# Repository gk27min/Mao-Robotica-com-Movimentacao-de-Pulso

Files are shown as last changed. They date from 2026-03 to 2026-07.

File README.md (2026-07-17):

# 🤖 Mão Robótica com Movimentação de Pulso — LIBRAS-BOT / FalaComaMão

> Protótipo de mão robótica de baixo custo, com cinco dedos funcionais e rotação de
> pulso, capaz de reproduzir configurações de mão (CMs) da **Língua Brasileira de Sinais
> (LIBRAS)** a partir de comandos de **voz ou texto**, interpretados por um modelo de
> linguagem (LLM) local.

Projeto desenvolvido para a disciplina de **Projeto Integrado em Computação II (PIC2)**
do curso de **Engenharia de Computação** da **Universidade Federal do Espírito Santo
(UFES)**.

**Status do projeto:** ✅ **Finalizado / funcional.**

🔗 **Repositório público (GitHub):**
<https://github.com/gk27min/Mao-Robotica-com-Movimentacao-de-Pulso>

<p align="center">
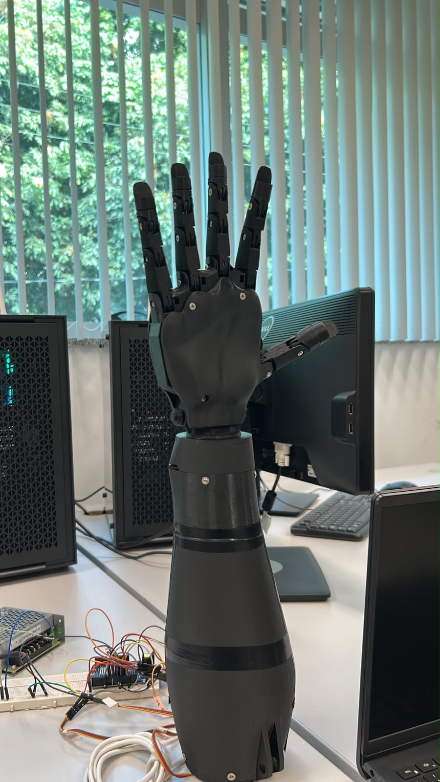
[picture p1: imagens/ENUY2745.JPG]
Protótipo montado da mão robótica com pulso
  
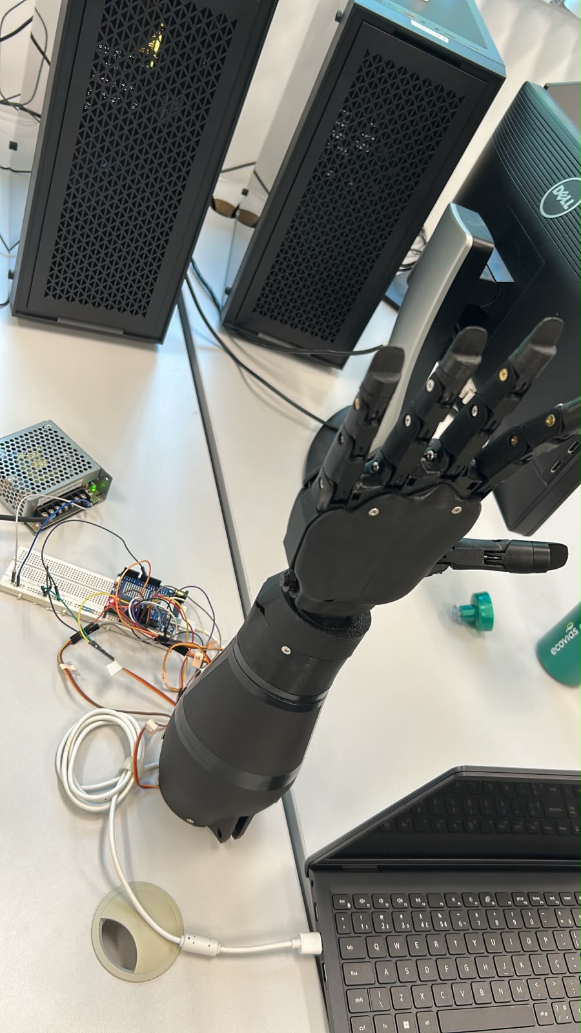
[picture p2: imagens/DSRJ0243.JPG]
Mão robótica conectada ao Arduino, fonte e notebook na bancada
  
</p>
<p align="center"><em>Protótipo final montado e a bancada de operação (Arduino Uno R4 WiFi, fonte, protoboard e servidor Python no notebook).</em></p>

---

## 📑 Índice

1. [Visão geral](#-visão-geral)
2. [Como funciona (fluxo end-to-end)](#-como-funciona-fluxo-end-to-end)
3. [Arquitetura do sistema](#-arquitetura-do-sistema)
4. [O que foi feito](#-o-que-foi-feito)
5. [O que foi usado (tecnologias)](#-o-que-foi-usado-tecnologias)
6. [Lista de equipamentos e componentes (BOM)](#-lista-de-equipamentos-e-componentes-bom)
7. [Hardware e ligações](#-hardware-e-ligações)
8. [Modelos 3D e peças impressas](#-modelos-3d-e-peças-impressas)
9. [Código-fonte — organização do repositório](#-código-fonte--organização-do-repositório)
10. [Guia de recriação (passo a passo)](#-guia-de-recriação-passo-a-passo)
11. [Biblioteca de gestos (CMs)](#-biblioteca-de-gestos-cms)
12. [Dificuldades de desenvolvimento](#-dificuldades-de-desenvolvimento)
13. [Vídeos e imagens de demonstração](#-vídeos-e-imagens-de-demonstração)
14. [Equipe e créditos](#-equipe-e-créditos)

---

## 🔎 Visão geral

A **FalaComaMão** é uma mão robótica antropomórfica impressa em 3D que traduz linguagem
natural em gestos de LIBRAS. O usuário fala ou digita uma frase no aplicativo; um LLM
rodando **localmente** interpreta a intenção e a converte em um código de gesto; esse
código é enviado por rede até um servidor Python, que o retransmite via **Bluetooth Low
Energy (BLE)** para um Arduino, o qual aciona os seis servomotores para reproduzir a
configuração de mão correspondente.

O foco do projeto é **acessibilidade e comunicação** a um **custo muito inferior** ao de
soluções comerciais, usando exclusivamente hardware aberto, impressão 3D e software livre.

---

## ⚙️ Como funciona (fluxo end-to-end)

```
┌─────────────┐   Voz/Texto   ┌──────────────────┐   HTTP/JSON   ┌─────────────────┐
│  App Flutter │ ────────────► │  Servidor Python │ ────────────► │  LLM local       │
│ (FalaComaMão)│   /api/comando│    (FastAPI)     │               │  Ollama (llama3.1)│
└─────────────┘               └──────────────────┘◄────────────  └─────────────────┘
       ▲                              │   código do gesto (ex.: 7)
       │ feedback no chat             │
       │                              ▼  BLE (bytearray[código])
       │                       ┌──────────────────┐    PWM     ┌─────────────────┐
       └───────────────────────│  Arduino Uno R4  │ ─────────► │ 6× Servo MG995   │
                               │      WiFi (BLE)  │            │ (5 dedos + pulso)│
                               └──────────────────┘            └─────────────────┘
```

1. **Captura** — o app captura a fala (Speech-to-Text nativo) ou o texto digitado.
2. **Interpretação** — o servidor Python envia a frase ao **Ollama**; o LLM escolhe **um
   único gesto** da biblioteca e responde no formato `GESTO: <ID>`. Há um *fallback* por
   palavras-chave caso o LLM não responda.
3. **Transmissão** — o servidor envia o código do gesto (1 byte) via **BLE** para o
   Arduino.
4. **Atuação** — o firmware decodifica o byte, resolve os ângulos de cada dedo/pulso e
   comanda os servomotores. Ao final, a mão retorna à posição de descanso.
5. **Feedback** — o app mostra o andamento no chat (*Analisando… → Mão executando → ✔*).

---

## 🏗️ Arquitetura do sistema

| Camada | Tecnologia | Papel |
|---|---|---|
| **Interface (mobile)** | Flutter / Dart | Chat multiplataforma, entrada por voz e texto, biblioteca de gestos |
| **Voz (STT)** | `speech_to_text` (Flutter) | Transcrição de áudio em tempo real |
| **Inteligência** | Ollama + `llama3.1` (LLM local) | Interpreta a intenção e escolhe o gesto |
| **Backend / ponte** | Python + FastAPI + Bleak | Orquestra a lógica e faz a ponte BLE com o Arduino |
| **Firmware** | C++ (Arduino) + `ArduinoBLE` + `Servo.h` | Recebe o código e aciona os servomotores |
| **Hardware** | Arduino Uno R4 WiFi + 6× MG995 | Estrutura física impressa em 3D com tração por fio de nylon |

---

## ✅ O que foi feito

- **Aplicativo mobile "FalaComaMão"** em Flutter, com duas telas: *Conversa* (chat com
  entrada por voz e texto) e *Biblioteca* (grade com todos os gestos disponíveis, com
  ícones animados que representam a configuração de cada mão).
- **Servidor intermediário em Python (FastAPI)** que expõe dois endpoints
  (`/api/comando` para linguagem natural e `/api/gesto` para envio direto de um código) e
  mantém uma conexão BLE persistente com reconexão automática.
- **Camada de inteligência** com *Prompt Engineering* sobre o Ollama para mapear frases
  livres em códigos de gesto, incluindo resolução de contas simples (ex.: "1 + 1" → gesto
  de dois dedos) e *fallback* determinístico por palavras-chave.
- **Firmware em C++** para o Arduino Uno R4 WiFi, que controla 6 servomotores via PWM,
  implementa gestos estáticos e gestos dinâmicos (com repetição de dedos e oscilação de
  pulso) e recebe comandos via BLE.
- **Estrutura física** impressa em 3D (PETG), com sistema de tração por fio de nylon e
  molas de retorno, adaptações de roldanas nos servos e caixa de pulso com rotação.
- **Biblioteca de ~20 configurações de mão (CMs)**, espelhada de forma idêntica entre app,
  backend e firmware (mesmos códigos em toda a stack).

<p align="center">
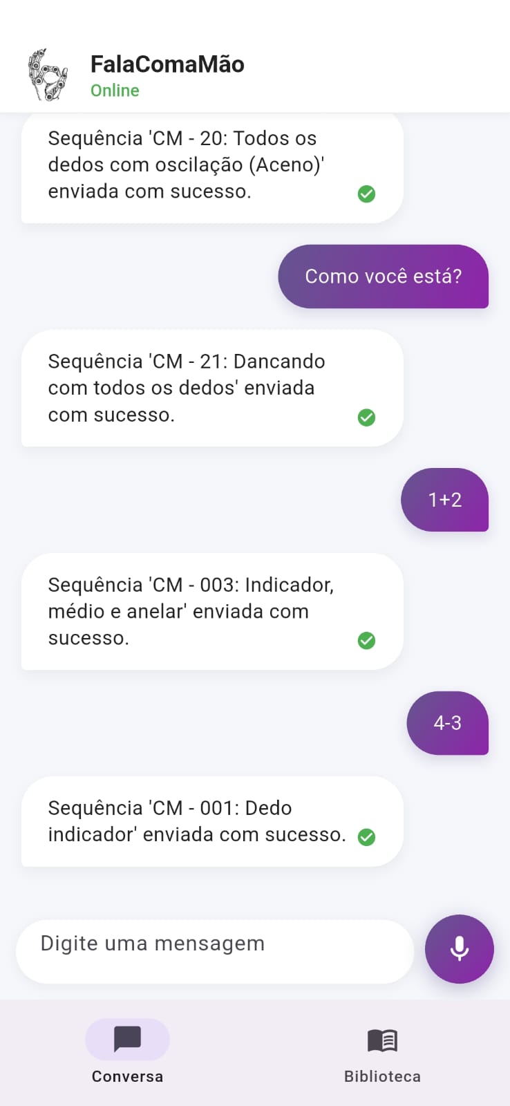
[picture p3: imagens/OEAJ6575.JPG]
Tela de conversa do app FalaComaMão
  
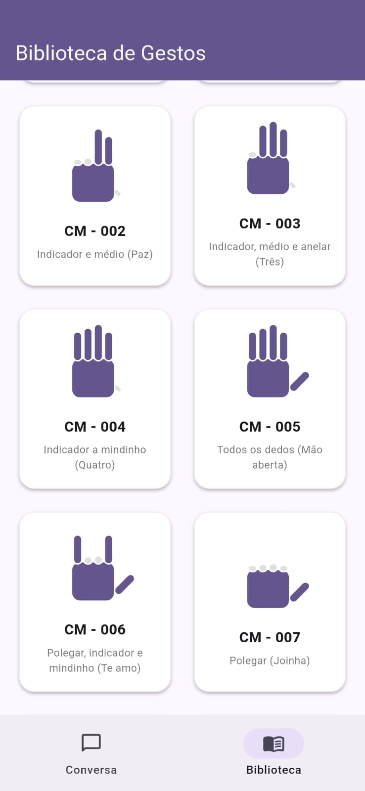
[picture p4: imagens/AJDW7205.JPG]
Tela biblioteca de gestos do app
  
</p>
<p align="center"><em>App FalaComaMão: tela de conversa (voz/texto) e biblioteca de gestos.</em></p>

---

## 🧰 O que foi usado (tecnologias)

**Software**

- **Flutter / Dart** — app multiplataforma (Android).
  Pacotes: `speech_to_text` (STT) e `http`.
- **Python 3.12** — backend.
  Pacotes principais: `fastapi`, `uvicorn`, `bleak` (BLE), `ollama`, `pydantic`
  (ver `backend/requirements.txt`).
- **Ollama** com o modelo **`llama3.1`** rodando localmente (sem nuvem).
- **C++ (Arduino IDE)** — firmware. Bibliotecas: `ArduinoBLE` e `Servo.h`.

**Protocolos e comunicação**

- **HTTP/JSON** entre app e servidor Python.
- **Bluetooth Low Energy (BLE / GATT)** entre servidor Python e Arduino.

**Fabricação**

- **Impressão 3D** em filamento **PETG**.
- Tração por **fio de nylon**, **molas de tração** sob medida e **roldanas** adaptadas.

---

## 📦 Lista de equipamentos e componentes (BOM)

### Eletrônica e atuadores

| Item | Especificação | Qtd. | Observação |
|---|---|:---:|---|
| **Microcontrolador** | **Arduino Uno R4 WiFi** | 1 | Comunicação por **BLE** com o servidor Python |
| **Servomotores** | **MG995** (torque metálico) | 6 | 5 dedos + 1 pulso, controlados por PWM |
| Fonte de alimentação | Fonte chaveada 5–6 V (corrente suficiente p/ 6 servos) | 1 | Alimenta os servos separadamente do Arduino |
| Protoboard | Padrão | 1 | Distribuição de alimentação e sinais |
| Jumpers / cabos | Macho-fêmea e macho-macho | — | Ligações de sinal e alimentação |
| Cabo USB | USB-C / USB | 1 | Programação e alimentação do Arduino |
| Smartphone Android | Físico (emulador não recomendado) | 1 | Roda o app; captura de áudio em tempo real |
| PC / notebook | Roda o servidor Python + Ollama | 1 | Precisa de BLE e estar na mesma rede do celular |

> ⚠️ Os servomotores devem ser alimentados por uma **fonte externa dedicada** (não pelos
> 5 V do Arduino), com **GND comum** entre a fonte e o Arduino. Seis MG995 sob carga
> podem exigir picos de corrente que a porta USB não fornece.

### Estrutura mecânica

| Item | Especificação | Qtd. |
|---|---|:---:|
| Filamento PETG | Preto | conforme impressão |
| **Fio de nylon** | Nylon **grosso** (~resistência de tração ≈ 50 kg) | rolo |
| **Molas de tração — dedos** | ver especificação em [Dificuldades](#-dificuldades-de-desenvolvimento) | 4 |
| **Molas de tração — polegar** | ver especificação em [Dificuldades](#-dificuldades-de-desenvolvimento) | 1 |
| Roldana / polia | 1 impressa sob medida + roldanas de fábrica dos servos | — |
| Parafusos | Diversos (fixação das peças) | — |

---

## 🔌 Hardware e ligações

### Microcontrolador

- **Arduino Uno R4 WiFi** — escolhido pela presença de **BLE nativo**, o que dispensa
  módulos externos de Bluetooth e permite receber os comandos diretamente do servidor
  Python.

### Mapa de pinos (servomotores → Arduino)

| Servo | Pino digital | Função |
|---|:---:|---|
| Pulso | **7** | Rotação/oscilação do pulso |
| Mindinho | **8** | Dedo mínimo |
| Anelar | **9** | Dedo anelar |
| Médio | **10** | Dedo médio |
| Indicador | **11** | Dedo indicador |
| Polegar | **12** | Polegar |

> **Lógica invertida (hardware):** por causa da montagem mecânica, mindinho/anelar/médio
> ficam **fechados a 180°** e **abertos a 0°**, enquanto o indicador é o oposto
> (**fechado a 0°**, **aberto a 180°**). Isso está documentado na função
> `configurarDedos()` do firmware.

### Comunicação BLE (GATT)

| Parâmetro | Valor |
|---|---|
| Nome do dispositivo | `MaoRobotica` |
| UUID do serviço | `19b10000-e8f2-537e-4f6c-d104768a1214` |
| UUID da característica (comando) | `19b10001-e8f2-537e-4f6c-d104768a1214` |
| Endereço MAC (exemplo do protótipo) | `b4:3a:45:b4:48:11` |
| Payload | 1 byte = código do gesto (ex.: `bytearray([7])`) |

> O MAC precisa ser atualizado em `backend/bluetooth_sender.py` para o do seu Arduino.

<p align="center">
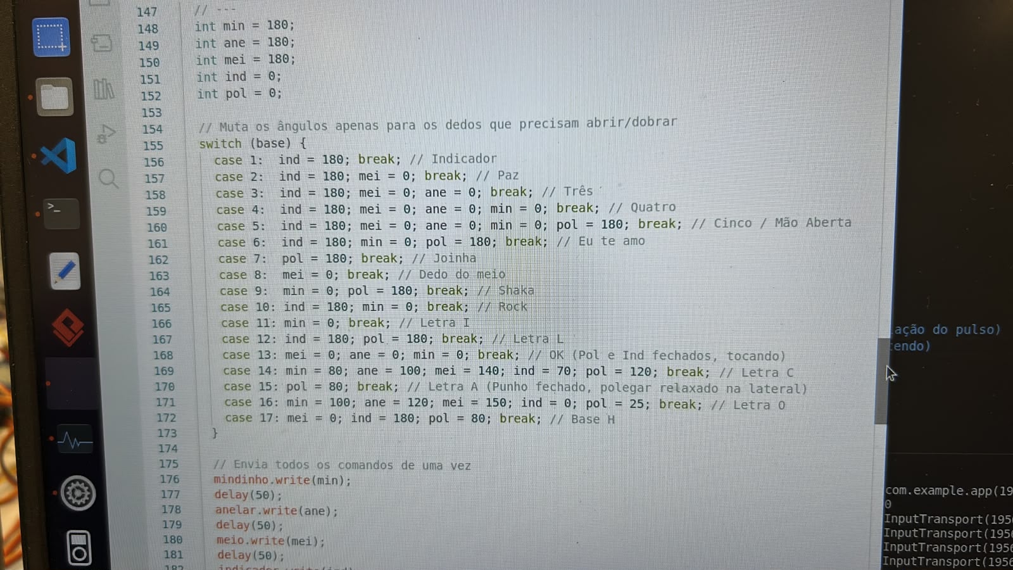
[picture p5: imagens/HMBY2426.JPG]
Trecho do firmware Arduino - configuração dos ângulos dos dedos
  
</p>
<p align="center"><em>Firmware C++: mapeamento de cada configuração de mão para os ângulos dos servos.</em></p>

---

## 🖨️ Modelos 3D e peças impressas

A estrutura mecânica é **impressa em 3D (PETG)** e parte do ecossistema aberto
**InMoov**, com **adaptações próprias** da equipe (roldana sob medida, ajustes de encaixe
e da caixa do pulso). Os arquivos `.stl` produzidos/utilizados estão versionados no
repositório em [`docs/3d_parts/`](docs/3d_parts).

<p align="center">
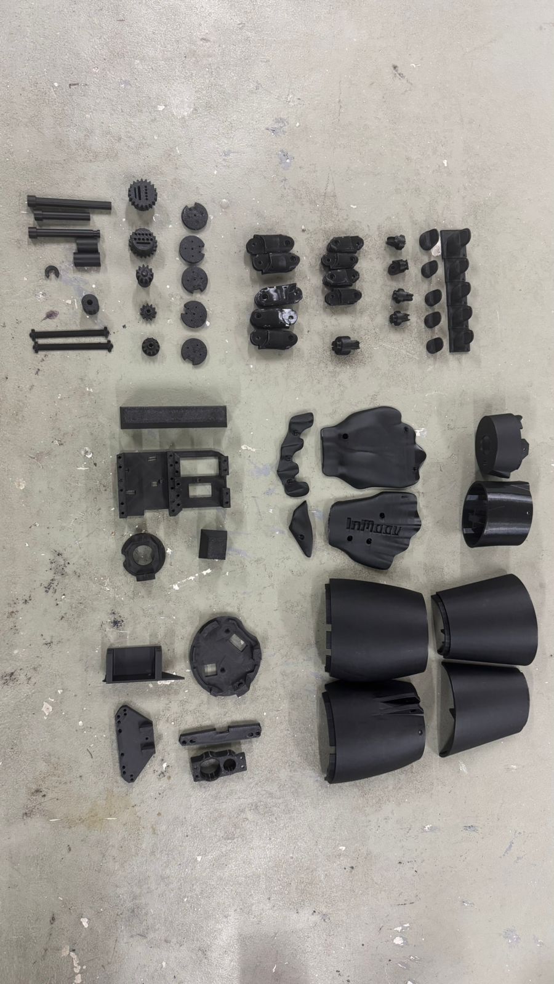
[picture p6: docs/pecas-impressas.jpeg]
Conjunto de peças impressas em 3D antes da montagem
  
</p>
<p align="center"><em>Conjunto de peças impressas em PETG antes da montagem (mão, dedos, pulso e suporte).</em></p>

**Mão e dedos — [`docs/3d_parts/mao/`](docs/3d_parts/mao)**

`i2_FingersX5V2`, `i2_FingersTipX5V2`, `i2_FingersMoldX5V3`, `i2_CoverFingerV3`,
`i2_HandCoverV1`, `i2_HandCoverV2`, `i2_PalmCoverV2`, `i2_WristGearV1`, `i2_WristLargeV2`.

**Pulso e antebraço — [`docs/3d_parts/pulso/`](docs/3d_parts/pulso)**

`robpart2V4`, `robpart3V4`, `robpart4V4`, `robpart5V4`, `robcap3V2`, `RobRingV3`,
`RobServoBedV6`, `RobCableFrontV3`, `RobCableBackV3`, `RotaWrist1V4`, `RotaWrist2V3`,
`RotaWrist3V3`, `WristGearsV5`, `Bolt_entretoise7`.

**Suporte — [`docs/3d_parts/suporte/`](docs/3d_parts/suporte)**

`Hand_stand.3mf` (base de apoio para exposição/testes).

---

## 🗂️ Código-fonte — organização do repositório

| Caminho | Linguagem / alvo | Descrição |
|---|---|---|
| [`app/`](app) | **Flutter / Dart** | Aplicativo mobile FalaComaMão |
| ↳ [`app/lib/main.dart`](app/lib/main.dart) | Dart | Interface completa: chat, STT, biblioteca de gestos e chamadas HTTP |
| [`backend/`](backend) | **Python (FastAPI)** | **Backend de produção** usado com o app |
| ↳ [`backend/server.py`](backend/server.py) | Python | API HTTP (`/api/comando`, `/api/gesto`) |
| ↳ [`backend/brain.py`](backend/brain.py) | Python | Mapeamento de intenção via LLM (Ollama) + fallback por keywords |
| ↳ [`backend/bluetooth_sender.py`](backend/bluetooth_sender.py) | Python | Ponte BLE (Bleak) com reconexão automática |
| ↳ [`backend/requirements.txt`](backend/requirements.txt) | — | Dependências do backend |
| [`server/`](server) | **Python (Flask)** | Protótipo inicial (etapa 1): Flask + Ollama + CRUD de sinais em `signs.json` |
| [`arduino/mao_robotica/mao_robotica.ino`](arduino/mao_robotica/mao_robotica.ino) | **C++ / Arduino Uno R4 WiFi** | **Firmware principal** (BLE + servos) |
| [`arduino/sinais_mao_robotica.ino`](arduino/sinais_mao_robotica.ino) | C++ / Arduino | Firmware alternativo focado em sinais |
| [`docs/`](docs) | — | Modelos 3D, esquemáticos, imagens e referências |

> **Nota sobre os dois servidores:** a pasta [`backend/`](backend) (FastAPI + BLE) é a que
> conversa com o app e com o Arduino no protótipo final. A pasta [`server/`](server)
> (Flask + Ollama) foi o **primeiro protótipo** da etapa de orquestração e é mantida como
> referência histórica.

---

## 🛠️ Guia de recriação (passo a passo)

### Pré-requisitos

- Impressora 3D e filamento **PETG**.
- **Arduino IDE** com a placa **Arduino Uno R4 WiFi** e as bibliotecas `ArduinoBLE` e
  `Servo`.
- **Python 3.12** e **Ollama** instalados no PC (com o modelo `llama3.1` baixado:
  `ollama pull llama3.1`).
- **Flutter SDK** e um **smartphone Android físico** (recomendado — o emulador tem
  incompatibilidades de microfone/KVM no Linux).

### 1. Fabricação e montagem mecânica

1. Imprima as peças de [`docs/3d_parts/`](docs/3d_parts) em PETG.
2. **Lixe os encaixes** que saírem imperfeitos da impressão (ver
   [Dificuldades](#-dificuldades-de-desenvolvimento)).
3. Passe o **fio de nylon grosso** pelos dedos e instale as **molas de tração** (specs
   abaixo).
4. Monte as **roldanas** nos servos (uma delas foi impressa sob medida sobre a roldana
   original do motor).
5. Fixe os 6 servos MG995 (5 dedos + pulso).

### 2. Firmware (Arduino)

1. Abra [`arduino/mao_robotica/mao_robotica.ino`](arduino/mao_robotica/mao_robotica.ino)
   na Arduino IDE.
2. Confira o [mapa de pinos](#mapa-de-pinos-servomotores--arduino) (pinos 7 a 12).
3. Carregue o firmware. No **Monitor Serial (9600 baud)** aparecerá o **endereço MAC** da
   placa — **anote-o**.

### 3. Backend (Python)

```bash
cd backend
python -m venv .venv
source .venv/bin/activate          # Linux/Mac  (Windows: .venv\Scripts\activate)
pip install -r requirements.txt
```

- Em [`backend/bluetooth_sender.py`](backend/bluetooth_sender.py), atualize o
  `MAC_ADDRESS` com o MAC anotado no passo anterior (e mantenha `MOCK_BLE = False` para
  usar o Arduino real).
- Garanta que o **Ollama** está rodando (`ollama serve`) com o `llama3.1` disponível.
- Suba o servidor:

```bash
uvicorn server:app --host 0.0.0.0 --port 5000 --reload
```

### 4. Aplicativo (Flutter)

1. Descubra o **IP do PC** na rede local (`ipconfig` no Windows / `ip a` no Linux).
2. Atualize esse IP em [`app/lib/main.dart`](app/lib/main.dart) (constantes `_serverUrl`
   e `serverUrl`, hoje em `http://192.168.1.4:5000`).
3. Ative a **depuração USB** no celular, conecte-o e rode:

```bash
cd app
flutter devices     # confirma que o celular foi reconhecido
flutter run
```

### 5. Teste end-to-end

- Fale ou digite "manda um joinha", "faz o sinal de paz", "abre a mão", "1 + 1"…
- A frase é interpretada, o código do gesto vai por BLE ao Arduino e a **mão executa** o
  movimento. O chat mostra o status até o ✔.

---

## ✋ Biblioteca de gestos (CMs)

Os códigos são **idênticos** no app, no backend e no firmware. Códigos **0–19** são
estáticos; **≥100** acionam também a **oscilação do pulso** (`código % 100` resolve a
configuração de dedos).

| Código | Configuração de mão | Exemplos de fala |
|:---:|---|---|
| 0 | Mão totalmente fechada (punho) | "fecha a mão", "3 − 3" |
| 1 | Dedo indicador | "aponta", "um" |
| 2 | Indicador e médio | "paz", "vitória", "1 + 1" |
| 3 | Indicador, médio e anelar | "três" |
| 4 | Indicador ao mindinho | "quatro" |
| 5 | Todos os dedos (mão aberta) | "abre a mão", "cinco", "pare" |
| 6 | Polegar, indicador e mindinho | "te amo", "ily" |
| 7 | Polegar | "joinha", "positivo", "valeu" |
| 9 | Polegar e mindinho | "hang loose", "telefone", "alô" |
| 10 | Indicador e mindinho | "rock", "metal" |
| 11 | Mindinho | "letra I" |
| 12 | Polegar e indicador | "letra L" |
| 13 | Médio, anelar e mindinho | "ok", "beleza", "perfeito" |
| 14–17 | Letras C, A, O e base do H | "letra C", "letra A", "letra O" |
| 18 | Sinal de água (indicador batendo) | "água", "beber" |
| 19 | Sinal de aspas (indicador e médio dobrando) | "aspas", "citação" |
| 20 / 105 | Todos os dedos com oscilação (aceno) | "oi", "olá", "tchau" |
| 100–119 | Versões dinâmicas (com oscilação do pulso) | — |

---

## 🧩 Dificuldades de desenvolvimento

Esta seção documenta honestamente os obstáculos enfrentados e as soluções adotadas — é a
parte mais valiosa para quem for **recriar** o projeto.

### 1. Fio de nylon

A movimentação dos dedos só ficou satisfatória usando um **fio de nylon mais grosso**,
com resistência de tração da ordem de **50 kg**. Fios mais finos não davam firmeza
suficiente ao movimento.

### 2. Molas de tração (sob medida)

As molas de retorno dos dedos têm um **tamanho muito específico** e **não foram
encontradas no mercado** — foi preciso **mandá-las fabricar**. Definir as propriedades
ideais foi um desafio: ângulos de gancho diferentes de **180° ou 0°** deixavam os dedos
**desalinhados** e o movimento "sujo". As especificações que funcionaram foram:

**Molas dos dedos normais** (quantidade: **4**)

| Propriedade | Valor |
|---|---|
| Diâmetro do arame (fio) | 0,5 mm |
| Diâmetro externo | 4,8 mm |
| Altura do corpo (sem ganchos) | 46 mm |
| Altura total (com ganchos) | 56 mm |
| Posição dos ganchos | alinhados (180°) |
| Material | aço carbono |
| Galvanizada | não |

**Mola do polegar (dedão)** (quantidade: **1**)

| Propriedade | Valor |
|---|---|
| Diâmetro do arame (fio) | 0,5 mm |
| Diâmetro externo | 4,8 mm |
| Altura do corpo (sem ganchos) | 42,5 mm |
| Altura total (com ganchos) | 52 mm |
| Posição dos ganchos | alinhados (180°) |
| Material | aço carbono |
| Galvanizada | não |

### 3. Roldanas (polias) dos servos

A **impressão da roldana não ficou perfeita** e o encaixe **não cabia no motor**. A
solução foi **fabricar uma roldana que se encaixa em volta da roldana original** que
acompanha o servo — assim o ajuste ficou perfeito.

### 4. Impressão 3D e estrutura

- Vários **encaixes precisaram ser lixados** após a impressão.
- As **partes centrais do braço não possuem parafusos**, o que consideramos um **ponto
  negativo** do projeto (perda de rigidez estrutural).
- A **caixa do motor do pulso não é bem estruturada** e possui uma **ponta que agarrou o
  fio de nylon** de um dos dedos, **tensionando demais o fio** — isso levou à **queima de
  um dos motores**. Recomendamos revisar/reforçar essa peça antes de operar sob carga.

---

## 🎬 Vídeos e imagens de demonstração

### Imagens

Todas na pasta [`imagens/`](imagens) e [`docs/`](docs):

| Arquivo | Conteúdo |
|---|---|
| [`imagens/ENUY2745.JPG`](imagens/ENUY2745.JPG) | Protótipo montado (mão aberta) |
| [`imagens/DSRJ0243.JPG`](imagens/DSRJ0243.JPG) | Bancada com Arduino, fonte e servidor |
| [`imagens/OEAJ6575.JPG`](imagens/OEAJ6575.JPG) | App — tela de conversa |
| [`imagens/AJDW7205.JPG`](imagens/AJDW7205.JPG) | App — biblioteca de gestos |
| [`imagens/HMBY2426.JPG`](imagens/HMBY2426.JPG) | Firmware — configuração dos dedos |
| [`docs/pecas-impressas.jpeg`](docs/pecas-impressas.jpeg) | Peças impressas em 3D |

### Vídeos

> Os vídeos de demonstração acompanham este repositório na pasta
> [`imagens/`](imagens). Substitua os nomes abaixo pelos arquivos reais:

| Vídeo | Conteúdo |
|---|---|
| `imagens/demo_voz.mp4` | Demonstração por **comando de voz** |
| `imagens/demo_gestos.mp4` | Execução de vários **gestos de LIBRAS** |
| `imagens/demo_pulso.mp4` | Movimentação/oscilação do **pulso** |

---

## 👥 Equipe e créditos

- Projeto acadêmico — **PIC2 · Engenharia de Computação · UFES**.
- Estrutura mecânica baseada no projeto de hardware aberto **InMoov**, com adaptações
  próprias da equipe.
- Licença: ver [`LICENSE`](LICENSE).

---

<p align="center"><em>FalaComaMão — tecnologia acessível a serviço da comunicação em LIBRAS.</em></p>

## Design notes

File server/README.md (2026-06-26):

# Backend Python — FalaComaMão / LIBRAS-BOT

Servidor intermediário que conecta o app Flutter, o **Ollama** (LLM local) e,
nas próximas etapas, o **Arduino R4 WiFi** via Bluetooth Low Energy.

## Arquitetura desta etapa (1)

```
  Flutter (texto NLP)
        │  HTTP POST /api/comando
        ▼
   app.py  ─────────────► ollama_client.py ──► Ollama (llama3.1:8b)
        │                                          │
        │◄─────── sinal escolhido + ângulos ───────┘
        │
        └── (etapa 4) BLE ──► Arduino R4 ──► servos
```

## Estrutura

| Arquivo | Função |
|---|---|
| `app.py` | Servidor Flask + endpoints REST |
| `ollama_client.py` | Cliente da API Ollama com prompt de classificação de intenção |
| `signs.json` | Sinais cadastrados (id, nome, descrição, sinônimos, ângulos) |
| `test_ollama.py` | REPL pra testar o cérebro sem precisar do Flutter nem do Arduino |
| `requirements.txt` | Dependências Python |

## Pré-requisitos

1. **Python 3.10+** (verifique com `python --version` no PowerShell).
2. **Ollama** rodando em `http://localhost:11434` com `llama3.1:8b` puxado:
   ```powershell
   ollama list      # deve aparecer llama3.1:8b
   ```

## Instalação

Abra o PowerShell na pasta `server/` e rode:

```powershell
# (Opcional, mas recomendado) crie um ambiente virtual:
python -m venv .venv
.\.venv\Scripts\Activate.ps1

# Instale as dependências:
pip install -r requirements.txt
```

> Se aparecer erro de execução de script no `Activate.ps1`, rode antes:
> `Set-ExecutionPolicy -Scope CurrentUser -ExecutionPolicy RemoteSigned`

## Teste rápido do cérebro (sem Flutter)

```powershell
python test_ollama.py
```

Digite frases — exemplos:

```
você> oi, tudo bem?         →  Oi  (id=oi)
você> falou, até mais         →  Tchau  (id=tchau)
você> show, beleza            →  OK  (id=ok)
você> que horas são?          →  nenhum sinal corresponde
```

Se isso funciona, a parte mais importante da etapa 1 está validada. ✔

## Rodando o servidor

```powershell
python app.py
```

Vai subir em `http://0.0.0.0:5000`. Pegue o IP do PC na rede (`ipconfig` →
"Endereço IPv4") e atualize a URL no Flutter em `app/lib/main.dart`.

### Endpoints disponíveis

| Método | Rota | O que faz |
|---|---|---|
| GET | `/api/status` | Saúde do servidor + Ollama |
| GET | `/api/sinais` | Lista os sinais cadastrados |
| POST | `/api/sinais` | Cadastra novo sinal (corpo JSON) |
| DELETE | `/api/sinais/<id>` | Remove um sinal |
| POST | `/api/comando` | Recebe texto → Ollama escolhe sinal → devolve ângulos |

### Exemplos de chamada (PowerShell)

Status:
```powershell
curl http://localhost:5000/api/status
```

Listar sinais:
```powershell
curl http://localhost:5000/api/sinais
```

Mandar um comando:
```powershell
curl -X POST http://localhost:5000/api/comando `
     -H "Content-Type: application/json" `
     -d '{"comando":"oi, tudo bem?"}'
```

Cadastrar um sinal novo:
```powershell
$body = @{
  id = "legal"
  nome = "Legal"
  descricao = "Sinalizar que algo é legal, maneiro, daora."
  sinonimos = @("daora","massa","maneiro","top")
  angulos = @{ polegar=180; indicador=0; medio=0; anelar=0; minimo=0; pulso=120 }
} | ConvertTo-Json
curl -X POST http://localhost:5000/api/sinais -H "Content-Type: application/json" -d $body
```

## Formato dos sinais (`signs.json`)

```jsonc
{
  "sinais": [
    {
      "id": "oi",                       // identificador único, snake_case
      "nome": "Oi",                     // exibição amigável
      "descricao": "Cumprimentar ...",  // o Ollama usa isso para decidir
      "sinonimos": ["olá", "salve"],    // ajuda o LLM a casar
      "angulos": {                      // 0..180 graus por servo
        "polegar": 0,
        "indicador": 180,
        "medio": 180,
        "anelar": 180,
        "minimo": 180,
        "pulso": 90
      }
    }
  ]
}
```

## Próximas etapas

- **2.** Telas de cadastro/biblioteca no Flutter consumindo `/api/sinais`.
- **3.** Firmware Arduino R4 com BLE + servos.
- **4.** Camada BLE no Python (`bleak`) — substituir o `TODO` em `app.py`.
- **5.** Polimento end-to-end (reconexão, feedback no app, logging).

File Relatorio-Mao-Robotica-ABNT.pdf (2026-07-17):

## UNIVERSIDADE FEDERAL DO ESPÍRITO SANTO CENTRO TECNOLÓGICO CURSO DE ENGENHARIA DE COMPUTAÇÃO

## DÉBORA AZEVEDO CAETANO GABRIELA BUTERI BELMOCK GESSICA DE SOUZA SILVA MARCOS VINICIUS DE SOUZA SILVA

# MÃO ROBÓTICA COM MOVIMENTAÇÃO DE PULSO

## Relatório técnico do projeto

## Vitória – ES

2026

## Débora Azevedo Caetano Gabriela Buteri Belmock Gessica de Souza Silva Marcos Vinicius de Souza Silva

# MÃO ROBÓTICA COM MOVIMENTAÇÃO DE PULSO

Relatório | técnico | apresentado | à

## disciplina de Projeto Integrado em Computação II (PIC2) do curso de

Engenharia | de | Computação | da
Universidade Federal do Espírito Santo, como requisito parcial de avaliação.

## Orientadores: Rodolfo da Silva Villaça e

Ricardo Carminati de Mello.

## Vitória – ES

2026

## SUMÁRIO

## APÊNDICE A – CÓDIGO-FONTE DO APLICATIVO (FLUTTER/DART)

APÊNDICE E – PROTÓTIPO INICIAL DO SERVIDOR (FLASK).........55

## 1 INTRODUÇÃO

## A comunicação por meio da Língua Brasileira de Sinais (LIBRAS) é

um direito das pessoas surdas e um pilar de acessibilidade. Entretanto,

dispositivos assistivos capazes de reproduzir sinais manuais ainda são caros e pouco acessíveis. Este relatório descreve o desenvolvimento de uma mão robótica de baixo custo, com cinco dedos funcionais e movimentação de pulso, capaz de reproduzir configurações de mão (CMs) empregadas em LIBRAS a partir de comandos em linguagem

natural, fornecidos por voz ou por texto.

O sistema integra hardware e software: uma estrutura mecânica impressa em 3D, acionada por seis servomotores; um microcontrolador que executa os movimentos; um servidor que interpreta a intenção do usuário com o apoio de um modelo de linguagem (LLM) executado localmente; e um aplicativo móvel que serve de interface. O protótipo

encontra-se finalizado e funcional.

## Figura 1 – Protótipo final montado


Fonte: os autores (2026).

## 1.1 Justificativa

## Soluções comerciais de mãos robóticas e próteses ativas possuem

custo elevado, o que limita seu uso em contextos educacionais e sociais. A proposta deste projeto é demonstrar que, com hardware aberto,

## impressão 3D e software livre, é possível construir um dispositivo

## funcional voltado à comunicação e à acessibilidade a uma fração do custo das alternativas de mercado, servindo também como plataforma

didática de robótica e sistemas embarcados.

## 1.2 Objetivos

## O objetivo geral é projetar e construir uma mão robótica capaz de reproduzir configurações de mão da LIBRAS a partir de comandos em linguagem natural. Como objetivos específicos, destacam-se: (i) desenvolver a estrutura mecânica impressa em 3D com dedos e pulso

articulados; (ii) implementar o firmware de controle dos servomotores;

## (iii) desenvolver o servidor de interpretação e a integração com um modelo de linguagem local; (iv) construir o aplicativo de interface com entrada por voz e por texto; e (v) integrar todas as camadas em um

fluxo funcional ponta a ponta.

## 1.3 Repositório do projeto

## Todo o código-fonte, os modelos 3D e a documentação estão disponíveis publicamente no repositório:

## github.com/gk27min/Mao-Robotica-com-Movimentacao-de-Pulso

## 2 VISÃO GERAL DO SISTEMA

## O sistema é organizado em camadas, da interface com o usuário até o acionamento físico dos motores. Cada camada tem uma responsabilidade bem definida e se comunica com a seguinte por um protocolo específico, o que facilita o teste e a manutenção de cada parte

de forma isolada.

## 2.1 Arquitetura

A arquitetura adotada é apresentada na Figura 2. O aplicativo captura a fala ou o texto do usuário e envia a frase, por HTTP, ao servidor Python. O servidor consulta um modelo de linguagem (LLM) executado localmente, que classifica a intenção e devolve o identificador do gesto correspondente. Em seguida, o servidor transmite esse identificador, por Bluetooth Low Energy (BLE), ao microcontrolador, que

aciona os servomotores por modulação por largura de pulso (PWM).

## Figura 2 – Arquitetura do sistema

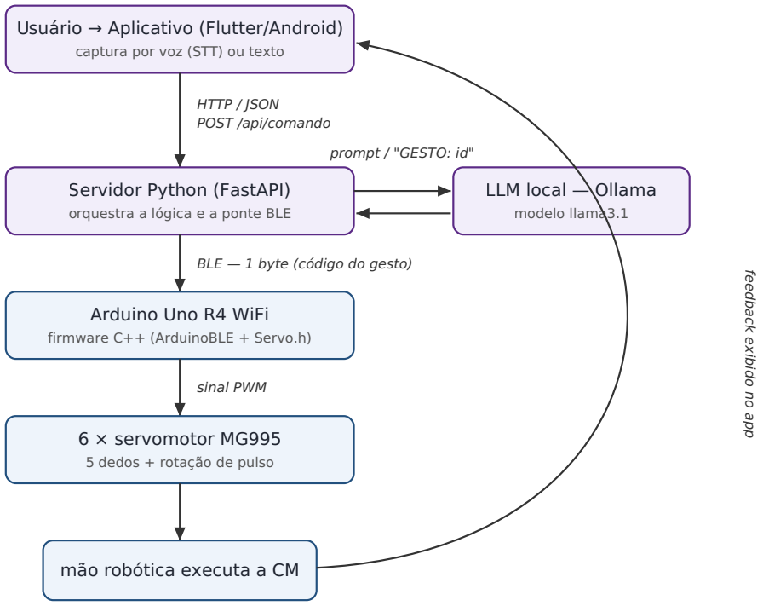
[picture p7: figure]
Usuário → Aplicativo (Flutter/Android); captura por voz (STT) ou texto; HTTP / JSON POST /api/comando; Servidor Python (FastAPI); orquestra a lógica e a ponte BLE; LLM local — Ollama; modelo llama3.1; prompt / "GESTO: id"; BLE — 1 byte (código do gesto); Arduino Uno R4 WiFi; firmware C++ (ArduinoBLE + Servo.h); sinal PWM; 6 × servomotor MG995; 5 dedos + rotação de pulso; mão robótica executa a CM; feedback exibido no app

Fonte: os autores (2026).

## 2.2 Fluxo de funcionamento

O funcionamento pode ser resumido em cinco etapas. Na captura,

o aplicativo obtém a fala (por reconhecimento de voz) ou o texto digitado. Na interpretação, o servidor envia a frase ao LLM, que escolhe um único gesto da biblioteca e responde no formato padronizado GESTO: <id>; caso o modelo não responda, um mecanismo de reserva por palavras-chave assume a decisão. Na transmissão, o servidor envia o código do gesto (um único byte) ao Arduino por BLE. Na atuação, o firmware decodifica o byte, calcula os ângulos de cada dedo e do pulso e comanda os motores; ao final, a mão retorna à posição de descanso. Por

fim, no retorno, o aplicativo exibe o andamento da operação ao usuário.

## 3 MATERIAIS E EQUIPAMENTOS

Esta seção relaciona os equipamentos, dispositivos eletrônicos, atuadores e materiais empregados na construção do protótipo.

## 3.1 Microcontrolador

O controle de baixo nível é realizado por um Arduino Uno R4 WiFi. Essa placa foi escolhida por oferecer Bluetooth Low Energy (BLE) nativo, o que dispensa módulos externos de comunicação sem fio e permite que o servidor envie os comandos diretamente à placa. O microcontrolador é responsável por receber o código do gesto, calcular

os ângulos e gerar os sinais PWM que acionam os servomotores.

## 3.2 Atuadores

Os movimentos são produzidos por seis servomotores MG995, de engrenagens metálicas: cinco deles tracionam os dedos (polegar,

## indicador, médio, anelar e mínimo) e um é responsável pela rotação/ oscilação do pulso. Os servos MG995 foram adotados por conciliarem torque adequado à tração dos dedos e baixo custo. Cada servo opera na

faixa de 0° a 180°, controlado por PWM a partir da biblioteca Servo.h.

## 3.3 Alimentação e componentes eletrônicos

Como seis servos sob carga demandam picos de corrente superiores ao que a porta USB fornece, os motores são alimentados por uma fonte externa dedicada, mantendo-se o GND comum com o Arduino. As ligações de sinal e de alimentação são distribuídas em uma protoboard, por meio de cabos jumper. O Quadro 1 relaciona os

componentes eletrônicos.

## Quadro 1 – Equipamentos e dispositivos eletrônicos

Item | Especificação | Qtd. | Função
Microcontrolador | Arduino Uno R4 WiFi | 1 | Controle e comunicação BLE
Servomotores | MG995 (engrenagem metálica) | 6 | 5 dedos + pulso (PWM)
Fonte de alimentação | Fonte chaveada (5–6 V, corrente p/ 6 servos) | 1 | Alimentação dos servos
Protoboard | Padrão | 1 | Distribuição de sinais e energia
Cabos jumper | Macho-macho / macho-fêmea | – | Ligações elétricas
Cabo USB | USB | 1 | Programação do Arduino
Smartphone Android | Aparelho físico | 1 | Executa o aplicativo (captura de voz)
Computador | PC/notebook com BLE | 1 | Executa o servidor e o LLM

Fonte: os autores (2026).

## 3.4 Estrutura mecânica e materiais

## A estrutura é impressa em filamento PETG e utiliza fio de nylon para a tração dos dedos, molas de tração para o retorno e roldanas acopladas aos servos. O Quadro 2 relaciona os materiais mecânicos. As especificações detalhadas das molas — cuja definição foi uma das

principais dificuldades do projeto — são apresentadas na Seção 7.2.

## Quadro 2 – Materiais da estrutura mecânica

Item | Especificação | Qtd.
Filamento | PETG (preto) | conforme impressão
Fio de nylon | Nylon grosso (tração ≈ 50 kg) | 1 rolo
Molas de tração — dedos | Aço carbono (ver Seção 7.2) | 4
Mola de tração — polegar | Aço carbono (ver Seção 7.2) | 1
Roldanas / polias | 1 impressa sob medida + roldanas dos servos | –
Parafusos | Diversos (fixação) | –

Fonte: os autores (2026).

## 4 PROJETO DE HARDWARE

## 4.1 Mapa de ligações (pinos)

Cada servomotor é conectado a um pino digital do Arduino,

conforme o Quadro 3. Em razão da montagem mecânica, a lógica de acionamento é invertida para parte dos dedos: mínimo, anelar e médio ficam fechados a 180° e abertos a 0°, enquanto o indicador adota o comportamento oposto (fechado a 0° e aberto a 180°). Essa convenção está implementada na função configurarDedos() do firmware (Apêndice

C).

## Quadro 3 – Mapa de pinos (servomotores → Arduino)

Servomotor | Pino digital | Função
Pulso | 7 | Rotação/oscilação do pulso
Mínimo | 8 | Dedo mínimo
Anelar | 9 | Dedo anelar
Médio | 10 | Dedo médio
Indicador | 11 | Dedo indicador
Polegar | 12 | Polegar

Fonte: os autores (2026).

## 4.2 Comunicação Bluetooth (BLE)

## A comunicação entre o servidor e o Arduino é feita por Bluetooth Low Energy, seguindo o modelo GATT. O firmware publica um serviço e uma característica, na qual o servidor escreve um único byte correspondente ao código do gesto. O Quadro 4 apresenta os

parâmetros de comunicação.

## Quadro 4 – Parâmetros da comunicação BLE

Nome do dispositivo | MaoRobotica
UUID do serviço | 19b10000-e8f2-537e-4f6c-d104768a1214
UUID da característica (comando) | 19b10001-e8f2-537e-4f6c-d104768a1214
Payload | 1 byte (código do gesto)

Fonte: os autores (2026).

## 4.3 Montagem eletrônica e projeto de placas

O protótipo não emprega uma placa de circuito impresso (PCI) dedicada: a montagem eletrônica foi realizada em protoboard, o que favorece a prototipagem, os testes e eventuais ajustes de ligação. A Figura 3 mostra a montagem, com o Arduino, a protoboard, a fonte de alimentação e o computador que executa o servidor. A migração para uma PCI dedicada é apontada como trabalho futuro para aumentar a

robustez das conexões.

## Figura 3 – Montagem eletrônica na bancada


Fonte: os autores (2026).

## 5 MODELOS 3D E FABRICAÇÃO

## A estrutura mecânica é totalmente impressa em 3D. Os modelos partem do projeto de hardware aberto InMoov e receberam adaptações próprias da equipe, descritas na Seção 7. Todos os arquivos .stl utilizados estão versionados no repositório, em docs/3d_parts/. A Figura 4

mostra o conjunto de peças impressas antes da montagem.

## Figura 4 – Peças impressas em 3D (PETG)


Fonte: os autores (2026).

## 5.1 Peças da mão e dos dedos

## Compreendem as falanges, as pontas dos dedos, os moldes, as

tampas | e | a | estrutura | da | palma. | Arquivos: | i2_FingersX5V2,
i2_FingersTipX5V2, i2_FingersMoldX5V3, i2_CoverFingerV3, i2_HandCoverV1, i2_HandCoverV2, i2_PalmCoverV2, i2_WristGearV1 e i2_WristLargeV2.

## 5.2 Peças do pulso e do antebraço

## Compreendem o mecanismo de rotação do pulso, o berço do

servo, as engrenagens e as guias de cabo. Arquivos: robpart2V4,
robpart3V4, robpart4V4, robpart5V4, robcap3V2, RobRingV3, RobServoBedV6, RobCableFrontV3, RobCableBackV3, RotaWrist1V4, RotaWrist2V3, RotaWrist3V3, WristGearsV5 e Bolt_entretoise7.

## 5.3 Suporte

Base de apoio para exposição e testes do conjunto: Hand_stand.3mf.

## 5.4 Impressão e montagem

## As peças foram impressas em PETG, material escolhido por sua resistência mecânica e tenacidade superiores às do PLA. Após a

impressão, parte dos encaixes precisou ser lixada para o ajuste correto.

## A montagem envolve a passagem do fio de nylon pelos dedos, a instalação das molas de retorno e o acoplamento das roldanas aos

servos — etapas detalhadas na Seção 7.

## 6 SOFTWARE E FIRMWARE

## O software está dividido em três blocos: o aplicativo de interface, o

servidor intermediário e o firmware embarcado. Os códigos completos,

## associados ao respectivo hardware de destino, encontram-se nos

Apêndices A a E.

## 6.1 Aplicativo de interface (Flutter)

O aplicativo é desenvolvido em Flutter (Dart) e executa em smartphone Android. Possui duas telas: a de conversa, no formato de chat, com entrada por voz (reconhecimento por meio do pacote speech_to_text) e por texto; e a de biblioteca, que exibe todas as configurações de mão em uma grade, com ícones animados. A comunicação com o servidor é feita por HTTP, usando o pacote http. As Figuras 5 e 6 apresentam as duas telas. O código completo está no

Apêndice A.

## Figura 5 – Aplicativo: tela de conversa

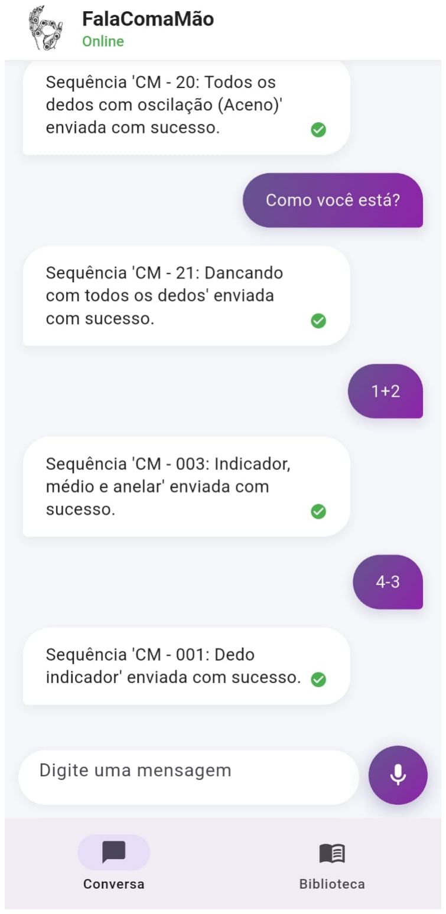
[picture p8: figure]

Fonte: os autores (2026).

## Figura 6 – Aplicativo: biblioteca de configurações de mão

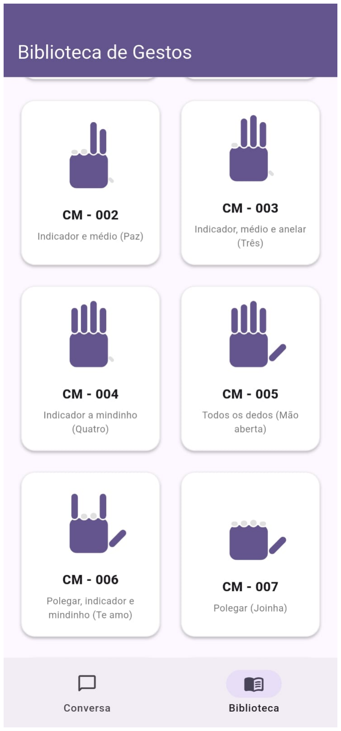
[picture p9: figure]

Fonte: os autores (2026).

## 6.2 Servidor intermediário (Python)

O servidor é escrito em Python, com o framework FastAPI, e executa no computador. Ele expõe dois endpoints: /api/comando, que recebe uma frase em linguagem natural e a submete ao LLM; e /api/ gesto, que recebe diretamente um código de gesto (utilizado pela tela de biblioteca). O servidor mantém uma conexão BLE persistente com o Arduino, com reconexão automática em caso de queda. O código

completo está no Apêndice B.

## 6.3 Inteligência: interpretação por LLM

A interpretação da linguagem natural é feita por um modelo de linguagem executado localmente por meio do Ollama (modelo llama3.1), sem dependência de serviços em nuvem. Por engenharia de prompt, o modelo é instruído a escolher exatamente um gesto da biblioteca e a responder em formato padronizado, sendo ainda capaz de resolver contas simples (por exemplo, "1 + 1" resulta na configuração de dois dedos). Quando o modelo não retorna um gesto válido, um

mecanismo de reserva baseado em palavras-chave assume a decisão, aumentando a robustez do sistema.

## 6.4 Firmware embarcado (C++)

O firmware, escrito em C++ para o Arduino Uno R4 WiFi, utiliza as bibliotecas ArduinoBLE e Servo.h. Ao receber um byte pela característica BLE, ele decodifica o código (valores acima de 100 acionam também a oscilação do pulso), resolve os ângulos de cada servo e executa o movimento, retornando a mão à posição de descanso ao final. O código completo está no Apêndice C; um segundo firmware, de testes por porta

serial, consta no Apêndice D.

## 6.5 Biblioteca de configurações de mão

## Os códigos das configurações de mão (CMs) são idênticos nas três camadas (aplicativo, servidor e firmware), garantindo coerência de

ponta a ponta. Os códigos de 0 a 19 correspondem a gestos estáticos;

## os iguais ou superiores a 100 acionam adicionalmente a oscilação do

pulso. O Quadro 5 apresenta um resumo.

## Quadro 5 – Exemplos de configurações de mão (CMs)

Código | Configuração | Exemplos de comando
0 | Mão fechada (punho) | "fecha a mão"; "3 − 3"
2 | Indicador e médio | "paz"; "1 + 1"
5 | Todos os dedos (mão aberta) | "abre a mão"; "cinco"
6 | Polegar, indicador e mínimo | "te amo"
7 | Polegar | "joinha"; "positivo"
13 | Médio, anelar e mínimo | "ok"; "beleza"
18 | Sinal de água (indicador batendo) | "água"; "beber"
20 / 105 | Mão aberta com oscilação (aceno) | "oi"; "tchau"

Fonte: os autores (2026).

## 7 DIFICULDADES DE DESENVOLVIMENTO

## Esta seção registra os principais obstáculos enfrentados e as soluções adotadas. Trata-se de informação essencial para quem

pretenda reproduzir o projeto.

## 7.1 Fio de nylon

## A qualidade do movimento dos dedos mostrou-se sensível ao tipo de fio de tração. Fios finos não conferiam firmeza suficiente. A solução foi adotar um fio de nylon mais grosso, com resistência de tração da ordem de 50 kg, com o qual a movimentação dos dedos ficou

adequada.

## 7.2 Molas de tração

As molas de retorno possuem dimensões muito específicas e não foram encontradas no mercado, sendo necessário mandá-las fabricar. A definição das propriedades ideais foi um desafio: ganchos com angulação diferente de 0° ou 180° deixavam os dedos desalinhados e o movimento irregular. As especificações que funcionaram são

apresentadas nos Quadros 6 e 7.

## Quadro 6 – Especificação das molas dos dedos (quantidade: 4)

Diâmetro do arame (fio) | 0,5 mm
Diâmetro externo | 4,8 mm
Altura do corpo (sem ganchos) | 46 mm
Altura total (com ganchos) | 56 mm
Posição dos ganchos | alinhados (180°)
Material | aço carbono
Galvanizada | não

Fonte: os autores (2026).

## Quadro 7 – Especificação da mola do polegar (quantidade: 1)

Diâmetro do arame (fio) | 0,5 mm
Diâmetro externo | 4,8 mm
Altura do corpo (sem ganchos) | 42,5 mm
Altura total (com ganchos) | 52 mm
Posição dos ganchos | alinhados (180°)
Material | aço carbono
Galvanizada | não

Fonte: os autores (2026).

## 7.3 Roldanas

## A impressão da roldana não resultou em um encaixe perfeito no eixo do servo. A solução foi fabricar uma roldana que se acopla em torno da roldana original que acompanha o motor, obtendo-se então

um ajuste firme e preciso.

## 7.4 Impressão e estrutura

Diversos encaixes precisaram ser lixados após a impressão. As partes centrais do braço não possuem parafusos, o que consideramos um ponto negativo por reduzir a rigidez estrutural. Além disso, a caixa do servo do pulso não é bem estruturada e possui uma saliência que chegou a prender o fio de nylon de um dos dedos, tensionando-o em excesso e provocando a queima de um dos motores. Recomenda-se

revisar e reforçar essa peça antes de operar o conjunto sob carga.

## 8 CONSIDERAÇÕES FINAIS

O projeto atingiu seus objetivos: foi construído um protótipo funcional de mão robótica capaz de reproduzir configurações de mão da LIBRAS a partir de comandos de voz ou texto, integrando estrutura mecânica impressa em 3D, firmware embarcado, servidor de interpretação com LLM local e aplicativo móvel. As dificuldades enfrentadas — sobretudo relativas ao fio de nylon, às molas sob medida e às roldanas — foram superadas e estão documentadas para permitir a reprodução do trabalho. Como trabalhos futuros, sugere-se a migração da eletrônica para uma placa de circuito impresso dedicada, o reforço da

caixa do pulso e a ampliação da biblioteca de gestos.

## REFERÊNCIAS

## ARDUINO. Arduino UNO R4 WiFi documentation. Disponível em: https://

docs.arduino.cc. Acesso em: 2026.

## FLUTTER. Flutter documentation. Disponível em: https://docs.flutter.dev. Acesso

em: 2026.

## INMOOV. InMoov – Open-source 3D printed life-size robot. Disponível em:

https://inmoov.fr. Acesso em: 2026.
OLLAMA. Ollama. Disponível em: https://ollama.com. Acesso em: 2026.

## APÊNDICE A – CÓDIGO-FONTE DO APLICATIVO (FLUTTER/DART)

Hardware de destino: smartphone Android. Arquivo: app/lib/main.dart.

import 'dart:convert';
import 'dart:math' as math;
import 'package:flutter/material.dart';
import 'package:flutter/services.dart';
import 'package:speech_to_text/speech_to_text.dart' as stt; import 'package:http/http.dart' as http;

void main() {
WidgetsFlutterBinding.ensureInitialized(); SystemChrome.setEnabledSystemUIMode(SystemUiMode.immersiveSticky); runApp(const FalaComaMaoApp());
}

Future<bool> enviarGestoDiretoParaServidor(int comando) async {
const String serverUrl = 'http://192.168.1.4:5000/api/gesto'; // <-- /api/gesto final url = Uri.parse(serverUrl);

try {
final response = await http.post(
url,
headers: {'Content-Type': 'application/json'}, body: jsonEncode({'comando': comando}), ).timeout(const Duration(seconds: 15));

if (response.statusCode == 200) {
print("Gesto $comando enviado com sucesso!");
return true;
} else {
print("Erro no servidor (${response.statusCode}): ${response.body}"); return false;
}
} catch (e) {
print("Erro ao enviar gesto: $e"); return false;
}
}

class FalaComaMaoApp extends StatelessWidget { const FalaComaMaoApp({super.key});

@override
Widget build(BuildContext context) { return MaterialApp(
title: 'FalaComaMão',
theme: ThemeData(
colorScheme: ColorScheme.fromSeed(
seedColor: const Color(0xFF6200EA), // Cor vibrante brightness: Brightness.light,
),
useMaterial3: true,
),
home: const MainNavigationScreen(), debugShowCheckedModeBanner: false, );
}
}

// ===================================================================== // NAVEGAÇÃO PRINCIPAL (Conversa / Biblioteca)
// ===================================================================== class MainNavigationScreen extends StatefulWidget {
const MainNavigationScreen({super.key});

@override
State<MainNavigationScreen> createState() => _MainNavigationScreenState(); }

class _MainNavigationScreenState extends State<MainNavigationScreen> {
int _selectedIndex = 0;

static const List<Widget> _screens = [

ChatScreen(),
SignsLibraryScreen(),
];

@override
Widget build(BuildContext context) {
return Scaffold(
body: IndexedStack(index: _selectedIndex, children: _screens), bottomNavigationBar: NavigationBar(
selectedIndex: _selectedIndex,
onDestinationSelected: (index) => setState(() => _selectedIndex = index), destinations: const [
NavigationDestination(
icon: Icon(Icons.chat_bubble_outline_rounded),
selectedIcon: Icon(Icons.chat_bubble_rounded), label: 'Conversa',
),
NavigationDestination(
icon: Icon(Icons.menu_book_outlined), selectedIcon: Icon(Icons.menu_book_rounded), label: 'Biblioteca',
),
],
),
);
}
}

// Classe estrutural para as mensagens class ChatMessage {
String text;
final bool isUser;
String status; // 'none', 'analyzing', 'done', 'error'

ChatMessage({
required this.text,
required this.isUser,
this.status = 'none',
});
}

class ChatScreen extends StatefulWidget {
const ChatScreen({super.key});

@override
State<ChatScreen> createState() => _ChatScreenState(); }

class _ChatScreenState extends State<ChatScreen> {
late stt.SpeechToText _speech;
bool _isListening = false;
bool _isProcessing = false;
String _recognizedText = '';

final TextEditingController _textController = TextEditingController(); final ScrollController _scrollController = ScrollController();

final List<ChatMessage> _messages = [
ChatMessage(text: 'Oi, Tudo Bem', isUser: false),
];

@override
void initState() {
super.initState();
_speech = stt.SpeechToText(); _textController.addListener(() => setState(() {})); }

@override
void dispose() {
_textController.dispose(); _scrollController.dispose(); super.dispose();
}

void _scrollToBottom() {
WidgetsBinding.instance.addPostFrameCallback((_) {

if (!_scrollController.hasClients) return; _scrollController.animateTo( _scrollController.position.maxScrollExtent, duration: const Duration(milliseconds: 250), curve: Curves.easeOut,
);
});
}

void _processFinalText(String text) {
if (text.isEmpty) return;

// 1. Adiciona a mensagem do usuário e a resposta provisória do robô setState(() {
_messages.add(ChatMessage(text: text, isUser: true)); _messages.add(ChatMessage(
text: 'Analisando...',
isUser: false,
status: 'analyzing',
));
_recognizedText = ''; // Limpa o buffer de reconhecimento
});
_scrollToBottom();

// 2. Chama a API passando o índice exato da mensagem do robô que deve ser atualizada final robotMessageIndex = _messages.length - 1;
enviarComandoParaServidor(text, robotMessageIndex);
}

void _sendTextMessage() {
if (_isProcessing) return;
final text = _textController.text.trim(); if (text.isEmpty) return;
_textController.clear();
_isProcessing = true;
_processFinalText(text);
}

void _cancelListening() {
HapticFeedback.lightImpact(); _speech.cancel();
setState(() {
_isListening = false;
_recognizedText = '';
});
}

void _listen() async {
// Bloqueia interações se já estiver processando if (_isProcessing) return;

if (!_isListening) {
bool available = await _speech.initialize( onStatus: (val) {
if (val == 'done' || val == 'notListening') {
setState(() => _isListening = false);
// Removido disparo manual. A responsabilidade agora é apenas do finalResult. }
},
onError: (val) {
print('onError: $val');
setState(() => _isListening = false); },
);

if (available) {
HapticFeedback.lightImpact(); setState(() {
_isListening = true;
_recognizedText = '';
});
_speech.listen(
onResult: (val) {
setState(() {
_recognizedText = val.recognizedWords;

});
// Trava de segurança: somente dispara se for finalResult E não estiver processando if (val.finalResult && !_isProcessing) {
setState(() => _isListening = false);
_isProcessing = true; // Trava o envio duplo _processFinalText(val.recognizedWords);
}
},
);
}
} else {
HapticFeedback.mediumImpact();
setState(() => _isListening = false);
_speech.stop();
// Removido disparo manual. A responsabilidade agora é apenas do finalResult. }
}

// Endereço IP do servidor Python na rede local.
static const String _serverUrl = 'http://192.168.1.4:5000/api/comando';

Future<void> enviarComandoParaServidor(String texto, int messageIndex) async { final url = Uri.parse(_serverUrl);

try {
final response = await http.post(
url,
headers: {'Content-Type': 'application/json'}, body: jsonEncode({'texto': texto}), ).timeout(const Duration(seconds: 60));

if (!mounted) return;

if (response.statusCode == 200) {
final data = jsonDecode(response.body) as Map<String, dynamic>; final sucesso = data['sucesso'] as bool;
final detalhes = data['detalhes'] as String;
final gestureName = data['comando_detectado'] as String?;

setState(() {
_isProcessing = false;
if (sucesso && gestureName != null) {
// Mostra primeiro que a mão está atuando; o texto final substitui em seguida. _messages[messageIndex].text = 'Mão executando o gesto: $ {gestureName.toUpperCase()}...'; _messages[messageIndex].status = 'acting';
} else {
_messages[messageIndex].text = sucesso ? detalhes : 'Não reconheci. $detalhes'; _messages[messageIndex].status = sucesso ? 'done' : 'error';
}
});
_scrollToBottom();

if (sucesso && gestureName != null) { _finishHandActing(messageIndex, detalhes); } else if (!sucesso) {
HapticFeedback.vibrate();
}
} else {
setState(() {
_messages[messageIndex].text = 'Erro no servidor (${response.statusCode}).'; _messages[messageIndex].status = 'error';
_isProcessing = false;
});
HapticFeedback.vibrate();
}
} catch (e) {
if (!mounted) return;
setState(() {
_messages[messageIndex].text = 'Servidor inacessível. Verifique a conexão.'; _messages[messageIndex].status = 'error';
_isProcessing = false;
});
HapticFeedback.vibrate();
}
}

void _finishHandActing(int messageIndex, String detalhes) { HapticFeedback.mediumImpact();
// O servidor confirma apenas o envio do comando via Bluetooth, não o término do
// movimento físico — sem telemetria do Arduino, a duração aqui é uma estimativa de UX. Future.delayed(const Duration(seconds: 3), () {
if (!mounted) return;
if (_messages[messageIndex].status != 'acting') return;
setState(() {
_messages[messageIndex].text = detalhes; _messages[messageIndex].status = 'done';
});
_scrollToBottom();
});
}

@override
Widget build(BuildContext context) {
return Scaffold(
backgroundColor: const Color(0xFFF5F7FB), appBar: AppBar(
backgroundColor: Colors.white, elevation: 0,
surfaceTintColor: Colors.transparent, shadowColor: Colors.black12,
title: Row(
children: [
const CircleAvatar(
backgroundImage: AssetImage('assets/icon.jpg'), backgroundColor: Colors.transparent,
),
const SizedBox(width: 12),
const Column(
crossAxisAlignment: CrossAxisAlignment.start, children: [
Text(
'FalaComaMão',
style: TextStyle(
color: Colors.black87,
fontSize: 18,
fontWeight: FontWeight.bold, ),
),
Text(
'Online',
style: TextStyle(
color: Colors.green,
fontSize: 13,
fontWeight: FontWeight.w500, ),
),
],
),
],
),
bottom: PreferredSize(
preferredSize: const Size.fromHeight(1.0), child: Container(
color: Colors.grey[200],
height: 1.0,
),
),
),
body: Column(
children: [
Expanded(
child: ListView.builder(
controller: _scrollController,
padding: const EdgeInsets.all(16),
itemCount: _messages.length + ((_isListening || _recognizedText.isNotEmpty) ? 1 : 0),
itemBuilder: (context, index) {
// Mensagens renderizadas do histórico
if (index < _messages.length) { final msg = _messages[index]; return ChatBubble(
message: msg.text,
isMe: msg.isUser,

status: msg.status,
);
} else {
// A última bolha é flutuante (tempo real) para o que o usuário está falando if (_isListening && _recognizedText.isEmpty) {
return const ChatBubble(
child: TypingIndicator(),
isMe: true,
);
} else {
return ChatBubble(
message: _recognizedText,
isMe: true,
);
}
}
},
),
),
SafeArea(
top: false,
child: Padding(
padding: const EdgeInsets.fromLTRB(12, 4, 12, 12),
child: AnimatedSwitcher(
duration: const Duration(milliseconds: 200),
child: _isListening ? _buildRecordingBar() : _buildComposerBar(), ),
),
),
],
),
);
}

Widget _buildComposerBar() {
final hasText = _textController.text.trim().isNotEmpty; return Row(
key: const ValueKey('composer'), crossAxisAlignment: CrossAxisAlignment.end, children: [
Expanded(
child: Container(
constraints: const BoxConstraints(minHeight: 48, maxHeight: 120), padding: const EdgeInsets.symmetric(horizontal: 18, vertical: 6), decoration: BoxDecoration(
color: Colors.white,
borderRadius: BorderRadius.circular(28),
boxShadow: [
BoxShadow(
color: Colors.black.withOpacity(0.05), blurRadius: 8,
offset: const Offset(0, 2),
),
],
),
child: TextField(
controller: _textController, minLines: 1,
maxLines: 4,
enabled: !_isProcessing,
textCapitalization: TextCapitalization.sentences, decoration: const InputDecoration(
hintText: 'Digite uma mensagem',
border: InputBorder.none,
isCollapsed: true,
),
onSubmitted: (_) => _sendTextMessage(), ),
),
),
const SizedBox(width: 8),
GestureDetector(
onTap: _isProcessing ? null : (hasText ? _sendTextMessage : _listen), child: AnimatedContainer(
duration: const Duration(milliseconds: 200),
width: 52,
height: 52, decoration: BoxDecoration( shape: BoxShape.circle,
gradient: LinearGradient(
colors: _isProcessing
? [Colors.grey.shade400, Colors.grey.shade500]
: [Theme.of(context).colorScheme.primary, const Color(0xFF8E24AA)], begin: Alignment.topLeft,
end: Alignment.bottomRight,
),
boxShadow: [
BoxShadow(
color: Theme.of(context).colorScheme.primary.withOpacity(0.35), blurRadius: 12,
offset: const Offset(0, 4),
),
],
),
child: Icon(
hasText ? Icons.send_rounded : Icons.mic_rounded, color: Colors.white,
),
),
),
],
);
}

Widget _buildRecordingBar() {
return Container(
key: const ValueKey('recording'),
padding: const EdgeInsets.symmetric(horizontal: 6, vertical: 6), decoration: BoxDecoration(
color: Colors.white,
borderRadius: BorderRadius.circular(28),
boxShadow: [
BoxShadow(
color: Colors.black.withOpacity(0.05), blurRadius: 8,
offset: const Offset(0, 2),
),
],
),
child: Row(
children: [
IconButton(
icon: const Icon(Icons.delete_outline_rounded, color: Colors.black45), onPressed: _cancelListening,
tooltip: 'Cancelar',
),
Expanded(
child: _recognizedText.isEmpty
? const Padding(
padding: EdgeInsets.symmetric(horizontal: 8), child: WaveformIndicator(),
)
: Padding(
padding: const EdgeInsets.symmetric(horizontal: 8), child: Text(
_recognizedText,
maxLines: 1,
overflow: TextOverflow.ellipsis,
style: const TextStyle(color: Colors.black87), ),
),
),
const Padding(
padding: EdgeInsets.symmetric(horizontal: 4),
child: Text('Ouvindo...', style: TextStyle(color: Colors.black45, fontSize: 12)), ),
GestureDetector(
onTap: _listen,
child: Container(
width: 44,
height: 44,
decoration: const BoxDecoration(
shape: BoxShape.circle,
gradient: LinearGradient(colors: [Colors.redAccent, Colors.deepOrange]),

),
child: const Icon(Icons.stop_rounded, color: Colors.white), ),
),
],
),
);
}
}

class ChatBubble extends StatelessWidget { final String? message;
final Widget? child;
final bool isMe;
final String status;

const ChatBubble({
super.key,
this.message,
this.child,
required this.isMe,
this.status = 'none',
});

@override
Widget build(BuildContext context) {
final textStyle = TextStyle(
color: isMe ? Colors.white : Colors.black87, fontSize: 15,
height: 1.3,
);

// Constrói o conteúdo do balão com base no status da resposta do robô Widget content;
if (child != null) {
content = child!;
} else {
if (status == 'analyzing') { content = Row(
mainAxisSize: MainAxisSize.min, children: [
const SizedBox(
width: 16,
height: 16,
child: CircularProgressIndicator(
strokeWidth: 2,
color: Color(0xFF8E24AA), // Cor vibrante igual ao tema principal ),
),
const SizedBox(width: 12),
Flexible(child: Text(message ?? '', style: textStyle)), ],
);
} else if (status == 'acting') {
content = Row(
mainAxisSize: MainAxisSize.min,
children: [
const Icon(Icons.back_hand, size: 18, color: Color(0xFF8E24AA)), const SizedBox(width: 10),
Flexible(child: Text(message ?? '', style: textStyle)),
],
);
} else if (status == 'done') {
content = Row(
mainAxisSize: MainAxisSize.min,
crossAxisAlignment: CrossAxisAlignment.end,
children: [
Flexible(child: Text(message ?? '', style: textStyle)),
const SizedBox(width: 6),
const Icon(Icons.check_circle_rounded, size: 16, color: Colors.green), ],
);
} else if (status == 'error') {
content = Row(
mainAxisSize: MainAxisSize.min, crossAxisAlignment: CrossAxisAlignment.start, children: [

const Icon(Icons.error_outline_rounded, size: 18, color: Colors.redAccent), const SizedBox(width: 8),
Flexible(child: Text(message ?? '', style: textStyle)),
],
);
} else {
content = Text(message ?? '', style: textStyle); }
}

return Align(
alignment: isMe ? Alignment.centerRight : Alignment.centerLeft, child: Container(
margin: const EdgeInsets.only(bottom: 16),
padding: const EdgeInsets.symmetric(horizontal: 20, vertical: 14), constraints: BoxConstraints(
maxWidth: MediaQuery.of(context).size.width * 0.75,
minHeight: 48,
),
decoration: BoxDecoration(
gradient: isMe
? LinearGradient(
colors: [
Theme.of(context).colorScheme.primary, const Color(0xFF8E24AA),
],
begin: Alignment.topLeft,
end: Alignment.bottomRight,
)
: null,
color: isMe ? null : (status == 'error' ? const Color(0xFFFFF3F3) : Colors.white), borderRadius: BorderRadius.only(
topLeft: const Radius.circular(24),
topRight: const Radius.circular(24),
bottomLeft: Radius.circular(isMe ? 24 : 4),
bottomRight: Radius.circular(isMe ? 4 : 24),
),
border: status == 'error' ? Border.all(color: Colors.redAccent.withOpacity(0.3)) : null, boxShadow: [
BoxShadow(
color: isMe
? Theme.of(context).colorScheme.primary.withOpacity(0.2) : Colors.black.withOpacity(0.05),
blurRadius: 8,
offset: const Offset(0, 4),
),
],
),
child: content,
),
);
}
}

class TypingIndicator extends StatefulWidget {
const TypingIndicator({super.key});

@override
State<TypingIndicator> createState() => _TypingIndicatorState();
}

class _TypingIndicatorState extends State<TypingIndicator> with SingleTickerProviderStateMixin { late AnimationController _controller;

@override
void initState() {
super.initState();
_controller = AnimationController(
vsync: this,
duration: const Duration(milliseconds: 1200), )..repeat();
}

@override
void dispose() {
_controller.dispose();
super.dispose();

}

@override
Widget build(BuildContext context) {
return Padding(
padding: const EdgeInsets.symmetric(vertical: 4), child: Row(
mainAxisSize: MainAxisSize.min,
children: List.generate(3, (index) {
return AnimatedBuilder(
animation: _controller,
builder: (context, child) {
final delay = index * 0.2;
var val = (_controller.value - delay) % 1.0; if (val < 0) val += 1.0;

final offset = (val < 0.5)
? Curves.easeInOut.transform(val * 2)
: Curves.easeInOut.transform((1 - val) * 2);

return Transform.translate(
offset: Offset(0, -6 * offset),
child: child,
);
},
child: Container(
margin: const EdgeInsets.symmetric(horizontal: 3), width: 8,
height: 8,
decoration: const BoxDecoration(
color: Colors.white,
shape: BoxShape.circle,
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
// Indicador de forma de onda animado, usado na barra de gravação de áudio. class WaveformIndicator extends StatefulWidget {
const WaveformIndicator({super.key});

@override
State<WaveformIndicator> createState() => _WaveformIndicatorState();
}

class _WaveformIndicatorState extends State<WaveformIndicator> with SingleTickerProviderStateMixin {
late final AnimationController _controller;

@override
void initState() {
super.initState();
_controller = AnimationController(
vsync: this,
duration: const Duration(milliseconds: 900), )..repeat();
}

@override
void dispose() {
_controller.dispose();
super.dispose();
}

@override
Widget build(BuildContext context) { return SizedBox(
height: 24,
child: Row(
mainAxisSize: MainAxisSize.min, children: List.generate(5, (i) { return AnimatedBuilder(
animation: _controller, builder: (context, child) {
final t = (_controller.value + i * 0.18) % 1.0;
final height = 6 + 14 * (0.5 + 0.5 * math.sin(t * 2 * math.pi)); return Container(
margin: const EdgeInsets.symmetric(horizontal: 2),
width: 4,
height: height,
decoration: BoxDecoration(
color: const Color(0xFF8E24AA), borderRadius: BorderRadius.circular(2), ),
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
class SignsLibraryScreen extends StatelessWidget { const SignsLibraryScreen({super.key});

@override
Widget build(BuildContext context) {
// Lista 100% atualizada e espelhada com o backend e o Arduino (0 a 19 e 100 a 119) final List<Map<String, dynamic>> configuracoesMao = [
// --- BLOCO 1: ESTÁTICOS (Pulso Fixo) ---
{'comando': 0, 'titulo': 'CM - 000', 'descricao': 'Mão totalmente fechada'}, {'comando': 1, 'titulo': 'CM - 001', 'descricao': 'Dedo indicador'}, {'comando': 2, 'titulo': 'CM - 002', 'descricao': 'Indicador e médio'}, {'comando': 3, 'titulo': 'CM - 003', 'descricao': 'Indicador, médio e anelar'}, {'comando': 4, 'titulo': 'CM - 004', 'descricao': 'Indicador a mindinho'}, {'comando': 5, 'titulo': 'CM - 005', 'descricao': 'Todos os dedos'},
{'comando': 6, 'titulo': 'CM - 006', 'descricao': 'Polegar, indicador e mindinho'}, {'comando': 7, 'titulo': 'CM - 007', 'descricao': 'Polegar'},
{'comando': 8, 'titulo': 'CM - 008', 'descricao': 'Dedo médio'},
{'comando': 9, 'titulo': 'CM - 009', 'descricao': 'Polegar e mindinho'}, {'comando': 10, 'titulo': 'CM - 010', 'descricao': 'Indicador e mindinho'}, {'comando': 11, 'titulo': 'CM - 011', 'descricao': 'Mindinho'},
{'comando': 12, 'titulo': 'CM - 012', 'descricao': 'Polegar e indicador'}, {'comando': 13, 'titulo': 'CM - 013', 'descricao': 'Médio, anelar e mindinho'}, {'comando': 14, 'titulo': 'CM - 014', 'descricao': 'Letra C (Dedos curvados)'}, {'comando': 15, 'titulo': 'CM - 015', 'descricao': 'Letra A (Polegar lateral)'}, {'comando': 16, 'titulo': 'CM - 016', 'descricao': 'Letra O (Círculo)'},
{'comando': 17, 'titulo': 'CM - 017', 'descricao': 'Base para Letra H'},

// --- BLOCO 1.1: ESTÁTICOS COM MOVIMENTO DE DEDO ---
{'comando': 18, 'titulo': 'CM - 018', 'descricao': 'Sinal de Água (Indicador batendo)'}, {'comando': 19, 'titulo': 'CM - 019', 'descricao': 'Sinal de Aspas (Indicador e médio dobrando)'},

// --- BLOCO 2: DINÂMICOS (Com oscilação do pulso) ---
{'comando': 100, 'titulo': 'CM - 100', 'descricao': 'Mão fechada'},
{'comando': 101, 'titulo': 'CM - 101', 'descricao': 'Indicador (Não)'}, {'comando': 102, 'titulo': 'CM - 102', 'descricao': 'Indicador e médio'}, {'comando': 103, 'titulo': 'CM - 103', 'descricao': 'Três dedos'}, {'comando': 104, 'titulo': 'CM - 104', 'descricao': 'Quatro dedos'}, {'comando': 105, 'titulo': 'CM - 105', 'descricao': 'Mão aberta (Aceno)'}, {'comando': 106, 'titulo': 'CM - 106', 'descricao': 'Te amo balançando'}, {'comando': 107, 'titulo': 'CM - 107', 'descricao': 'Polegar'}, {'comando': 108, 'titulo': 'CM - 108', 'descricao': 'Dedo médio'}, {'comando': 109, 'titulo': 'CM - 109', 'descricao': 'Shaka balançando'}, {'comando': 110, 'titulo': 'CM - 110', 'descricao': 'Rock balançando'},
{'comando': 111, 'titulo': 'CM - 111', 'descricao': 'Mindinho'},
{'comando': 112, 'titulo': 'CM - 112', 'descricao': 'Polegar e indicador'},
{'comando': 113, 'titulo': 'CM - 113', 'descricao': 'Médio, anelar, mindinho balançando'}, {'comando': 114, 'titulo': 'CM - 114', 'descricao': 'Letra C balançando'},
{'comando': 115, 'titulo': 'CM - 115', 'descricao': 'Letra A balançando'},
{'comando': 116, 'titulo': 'CM - 116', 'descricao': 'Letra O balançando'},
{'comando': 117, 'titulo': 'CM - 117', 'descricao': 'Letra H (Base com rotação)'}, {'comando': 118, 'titulo': 'CM - 118', 'descricao': 'Sinal de Água do pulso'}, {'comando': 119, 'titulo': 'CM - 119', 'descricao': 'Sinal de Aspas do pulso'}, ];

return Scaffold(
appBar: AppBar(

title: const Text('Biblioteca de Gestos'), backgroundColor: Theme.of(context).colorScheme.primary, foregroundColor: Colors.white,
),
body: GridView.builder(
padding: const EdgeInsets.all(16),
gridDelegate: const SliverGridDelegateWithMaxCrossAxisExtent( maxCrossAxisExtent: 200,
crossAxisSpacing: 16,
mainAxisSpacing: 16,
childAspectRatio: 0.85,
),
itemCount: configuracoesMao.length, itemBuilder: (context, index) { final cm = configuracoesMao[index];

return InkWell(
onTap: () async {
final messenger = ScaffoldMessenger.of(context); // captura antes do await final titulo = cm['titulo'] as String;

messenger.showSnackBar(
SnackBar(content: Text('Enviando $titulo...')),
);

final ok = await enviarGestoDiretoParaServidor(cm['comando'] as int);

messenger.hideCurrentSnackBar();
messenger.showSnackBar(
SnackBar(
content: Text(ok ? '$titulo enviado!' : 'Falha ao enviar $titulo'), backgroundColor: ok ? Colors.green : Colors.red,
),
);
},
child: Card(
elevation: 2,
color: Colors.white,
shape: RoundedRectangleBorder(
borderRadius: BorderRadius.circular(16),
side: BorderSide(color: Colors.grey.shade200, width: 1),
),
child: Padding(
padding: const EdgeInsets.symmetric(horizontal: 8, vertical: 12), child: Column(
mainAxisAlignment: MainAxisAlignment.center,
children: [
HandGestureIcon(
gestureLevel: cm['comando'] as int, size: 80,
),
const SizedBox(height: 16),
Text(
cm['titulo'] as String,
style: const TextStyle(fontWeight: FontWeight.w800, fontSize: 15), ),
const SizedBox(height: 6),
Text(
cm['descricao'] as String,
textAlign: TextAlign.center,
style: TextStyle(color: Colors.grey.shade600, fontSize: 11), ),
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
class RegisterSignScreen extends StatelessWidget { const RegisterSignScreen({super.key});

@override

Widget build(BuildContext context) { return Scaffold(
appBar: AppBar(
title: const Text('Cadastrar Sinal'),
backgroundColor: Theme.of(context).colorScheme.primary, foregroundColor: Colors.white,
),
body: const Center(
child: Text('Formulário de cadastro', style: TextStyle(fontSize: 18)), ),
);
}
}

// Transformado em StatefulWidget para suportar o Loop de animação dos dedos class HandGestureIcon extends StatefulWidget {
final int gestureLevel;
final double size;

const HandGestureIcon({
super.key,
required this.gestureLevel, this.size = 100.0,
});

@override
State<HandGestureIcon> createState() => _HandGestureIconState();
}

class _HandGestureIconState extends State<HandGestureIcon> with SingleTickerProviderStateMixin { late AnimationController _fingerController;

@override
void initState() {
super.initState();
// Controlador de animação que vai e volta (looping infinito) _fingerController = AnimationController(
vsync: this,
duration: const Duration(milliseconds: 500), )..repeat(reverse: true);
}

@override
void dispose() {
_fingerController.dispose(); super.dispose();
}

@override
Widget build(BuildContext context) {
final activeColor = Theme.of(context).colorScheme.primary; final inactiveColor = Colors.grey.shade300;

final int baseGesture = widget.gestureLevel % 100;
final bool hasWristMovement = widget.gestureLevel >= 100;

// Estados dos dedos: 0 = Fechado, 1 = Aberto, 2 = Curvado (metade), 3 = Batendo (loop) int ind = 0, mei = 0, ane = 0, min = 0, pol = 0;

switch (baseGesture) {
case 1: ind = 1; break;
case 2: ind = 1; mei = 1; break;
case 3: ind = 1; mei = 1; ane = 1; break;
case 4: ind = 1; mei = 1; ane = 1; min = 1; break;
case 5: ind = 1; mei = 1; ane = 1; min = 1; pol = 1; break; case 6: ind = 1; min = 1; pol = 1; break;
case 7: pol = 1; break;
case 8: mei = 1; break;
case 9: min = 1; pol = 1; break;
case 10: ind = 1; min = 1; break;
case 11: min = 1; break;
case 12: ind = 1; pol = 1; break;
case 13: mei = 1; ane = 1; min = 1; break;
case 14: ind = 2; mei = 2; ane = 2; min = 2; pol = 2; break; // Letra C (Curvados) case 15: pol = 2; break; // Letra A (Apenas polegar lateral relaxado)
case 16: ind = 0; mei = 2; ane = 2; min = 2; pol = 2; break; // Letra O (Círculo) case 17: ind = 1; pol = 2; break; // Base H (Indicador aberto, polegar metade)

case 18: ind = 3; break; // Água (Indicador batendo repetidamente) case 19: ind = 3; mei = 3; break; // Aspas (Indicador e médio batendo) }

final fw = widget.size * 0.13;
final palmWidth = widget.size * 0.55;
final palmHeight = widget.size * 0.50;

return SizedBox(
width: widget.size,
height: widget.size,
child: Stack(
clipBehavior: Clip.none,
children: [
// Polegar
Positioned(
bottom: widget.size * 0.18, right: widget.size * 0.15,
child: Transform.rotate(
angle: 0.78,
alignment: Alignment.bottomLeft,
child: _buildRoboticFinger(pol, activeColor, inactiveColor, fw, widget.size * 0.35), ),
),

// Chassi da Mão
Positioned(
bottom: widget.size * 0.05, left: widget.size * 0.20,
child: Container(
width: palmWidth,
height: palmHeight,
decoration: BoxDecoration(
color: activeColor,
borderRadius: BorderRadius.circular(widget.size * 0.1), ),
),
),

// Os 4 dedos superiores
Positioned(
bottom: widget.size * 0.52, left: widget.size * 0.20,
child: SizedBox(
width: palmWidth,
child: Row(
mainAxisAlignment: MainAxisAlignment.spaceEvenly,
crossAxisAlignment: CrossAxisAlignment.end,
children: [
_buildRoboticFinger(min, activeColor, inactiveColor, fw, widget.size * 0.40), _buildRoboticFinger(ane, activeColor, inactiveColor, fw, widget.size * 0.45), _buildRoboticFinger(mei, activeColor, inactiveColor, fw, widget.size * 0.50), _buildRoboticFinger(ind, activeColor, inactiveColor, fw, widget.size * 0.40), ],
),
),
),

// Indicador de Movimento do Pulso if (hasWristMovement)
Positioned(
top: -widget.size * 0.15,
right: -widget.size * 0.15, child: Icon(
Icons.autorenew_rounded,
color: activeColor,
size: widget.size * 0.30,
),
),
],
),
);
}

// O desenho de cada dedo agora reage aos 4 estados
Widget _buildRoboticFinger(int state, Color activeColor, Color inactiveColor, double width, double maxHeight) {

return AnimatedBuilder(
animation: _fingerController,
builder: (context, child) {
double currentHeight = maxHeight * 0.25; // Altura base (Fechado) Color currentColor = inactiveColor;

if (state == 1) {
// Totalmente Aberto
currentHeight = maxHeight;
currentColor = activeColor;
} else if (state == 2) {
// Curvado (Metade da altura) - Efeito de pintura pela metade currentHeight = maxHeight * 0.55;
currentColor = activeColor;
} else if (state == 3) {
// Batendo (Loop que varia a altura do dedo para cima e para baixo) // Varia de 25% (fechado) a 100% (aberto)
currentHeight = maxHeight * (0.25 + (0.75 * _fingerController.value));
// Faz a cor acender e apagar durante a batida
currentColor = Color.lerp(inactiveColor, activeColor, _fingerController.value) ?? activeColor;
}

return Container(
width: width,
height: currentHeight,
decoration: BoxDecoration(
color: currentColor,
borderRadius: BorderRadius.circular(width / 2), border: Border.all(
color: Colors.white,
width: 1.5,
),
),
);
}
);
}
}

## Dependências (arquivo app/pubspec.yaml): flutter, speech_to_text ^7.0.0, http

^1.1.0, cupertino_icons ^1.0.8.

## APÊNDICE B – CÓDIGO-FONTE DO SERVIDOR (PYTHON)

## Hardware de destino: computador (PC/notebook). Servidor de produção (FastAPI +

BLE).

Arquivo: backend/server.py.

import logging
import uvicorn
import asyncio
from typing import Optional
from contextlib import asynccontextmanager # 1. ADICIONADO AQUI from fastapi import FastAPI
from fastapi.middleware.cors import CORSMiddleware
from pydantic import BaseModel

# Importação dos módulos internos

from brain import MapeadorDeSinais, GESTOS
from bluetooth_sender import enviar_comando_bluetooth, conectar_bluetooth, desconectar_bluetooth

# Configuração de Logs

logging.basicConfig(level=logging.INFO)
logger = logging.getLogger("server")

# 2. COLOQUE A FUNÇÃO LIFESPAN AQUI (Substituindo os antigos @app.on_event) @asynccontextmanager

async def lifespan(app: FastAPI):
# O que acontece no startup:

await conectar_bluetooth() yield
# O que acontece no shutdown:

await desconectar_bluetooth()

# 3. PASSAR O LIFESPAN DENTRO DO FASTAPI

app = FastAPI(
title="LIBRAS-BOT Backend",
description="Servidor intermediário em Python (FalaComaMão) para processamento de voz e ponte BLE.",
version="1.0.0",
lifespan=lifespan # ADICIONADO AQUI
)

# Configuração de CORS (Cross-Origin Resource Sharing) app.add_middleware(

CORSMiddleware,
allow_origins=["*"],
allow_credentials=True,
allow_methods=["*"],
allow_headers=["*"],
)

# Inicialização do Mapeador de Sinais (Zero-DB)

mapeador = MapeadorDeSinais()

# ===================================================================== # MODELOS DE DADOS (Pydantic)

# ===================================================================== class ComandoRequest(BaseModel):

texto: str

class GestoRequest(BaseModel):
comando: int

class ComandoResponse(BaseModel):
sucesso: bool
texto_original: str
comando_detectado: Optional[str] = None codigo: Optional[int] = None
confianca: float
detalhes: str

# ===================================================================== # ENDPOINTS

# =====================================================================

@app.get("/")
def read_root():
return {"status": "online", "servico": "LIBRAS-BOT Backend"}

@app.post("/api/comando", response_model=ComandoResponse)
async def processar_comando(requisicao: ComandoRequest):
texto = requisicao.texto
logger.info(f"Requisição recebida com texto de voz: '{texto}'")

# 1. 'codigos' agora recebe uma LISTA

codigos, descricao, similaridade = await mapeador.processar_comando(texto)

if not codigos: # Se a lista estiver vazia
detalhes = "Comando não compreendido pela IA."
return ComandoResponse(sucesso=False, texto_original=texto, confianca=0.0, detalhes=detalhes)

logger.info(f"Comandos compreendidos: {descricao} (Códigos: {codigos})")

# 2. Camada de Comunicação: Envia a sequência com delay

for cod in codigos:
if cod == -1:
logger.warning("Sinal de erro/inválido ignorado na sequência.") continue

envio_sucesso = await enviar_comando_bluetooth(cod)

if not envio_sucesso:
# Se falhar no meio da sequência, aborta o resto

detalhes = f"Falha ao enviar o código {cod} via Bluetooth." logger.error(detalhes)
return ComandoResponse(
sucesso=False, texto_original=texto, comando_detectado=descricao, confianca=similaridade, detalhes=detalhes
)

# Pausa vital para o Arduino executar o movimento físico (4 segundos)

# Usar asyncio.sleep previne que o servidor inteiro trave durante a pausa await asyncio.sleep(4)

# 3. Retorno com Sucesso

detalhes = f"Sequência '{descricao}' enviada com sucesso."
return ComandoResponse(
sucesso=True, texto_original=texto, comando_detectado=descricao, confianca=similaridade, detalhes=detalhes
)

@app.post("/api/gesto", response_model=ComandoResponse)
async def enviar_gesto_direto(requisicao: GestoRequest):
codigo = requisicao.comando
logger.info(f"Gesto direto recebido da biblioteca: {codigo}")

# Valida se o código existe na biblioteca

if codigo not in GESTOS:
detalhes = f"Código de gesto {codigo} não existe na biblioteca."
return ComandoResponse(
sucesso=False, texto_original=str(codigo), confianca=0.0, detalhes=detalhes )

descricao = GESTOS[codigo][0]

# Envia direto pro Bluetooth, sem passar pela LLM

envio_sucesso = await enviar_comando_bluetooth(codigo)

if not envio_sucesso:
detalhes = f"Falha ao enviar o gesto {codigo} via Bluetooth."
return ComandoResponse(
sucesso=False, texto_original=str(codigo), comando_detectado=descricao, codigo=codigo, confianca=1.0, detalhes=detalhes
)

detalhes = f"Gesto '{descricao}' enviado com sucesso."
return ComandoResponse(
sucesso=True, texto_original=str(codigo), comando_detectado=descricao, codigo=codigo, confianca=1.0, detalhes=detalhes
)

if __name__ == "__main__":
uvicorn.run("server:app", host="0.0.0.0", port=5000, reload=True)

Arquivo: backend/brain.py.

import re
import logging
import ollama
from typing import Optional, Tuple

logging.basicConfig(level=logging.INFO)
logger = logging.getLogger("brain")

# Gestos disponíveis: ID → (Descrição semântica e física, palavras-chave para fallback) GESTOS = {

# ==========================================

# BLOCO 1: ESTÁTICOS (Pulso Fixo) -> 0 a 17

# ==========================================

0: ("CM - 000: Mão totalmente fechada", ["fechar", "punho", "zero", "fechada"]),
1: ("CM - 001: Dedo indicador", ["apontar", "indicador", "ponto", "direção", "um", "1"]), 2: ("CM - 002: Indicador e médio", ["paz", "vitoria", "vitória", "peace", "victory"]),
3: ("CM - 003: Indicador, médio e anelar", ["tres", "três"]),
4: ("CM - 004: Indicador, médio, anelar e mindinho", ["quatro"]),
5: ("CM - 005: Todos os dedos", ["abrir", "aberta", "estender", "todos", "dedos", "cinco", "espalmar", "pare", "descanso", "repouso", "posição inicial"]),
6: ("CM - 006: Polegar, indicador e mindinho", ["amo", "love", "te amo", "ily"]),
7: ("CM - 007: Polegar", ["joinha", "positivo", "bom", "legal", "like", "curtir", "polegar", "valeu"]),
8: ("CM - 008: Dedo médio", ["dedo do meio", "ofensivo", "médio", "xingamento"]),
9: ("CM - 009: Polegar e mindinho", ["hanglose", "hang loose", "shaka", "surf", "surfista", "telefone", "alô"]),
10: ("CM - 010: Indicador e mindinho", ["rock", "metal", "chifres", "horns"]),
11: ("CM - 011: Mindinho", ["letra i", "libras i", "mindinho"]),
12: ("CM - 012: Polegar e indicador", ["letra l", "libras l", "loser", "faz o l"]),
13: ("CM - 013: Médio, anelar e mindinho", ["ok", "certo", "tudo certo", "concordo", "beleza", "perfeito"]),
14: ("CM - 014: Letra C em LIBRAS (Dedos curvados)", ["letra c", "libras c"]),
15: ("CM - 015: Letra A em LIBRAS", ["letra a", "libras a"]),
16: ("CM - 016: Letra O em LIBRAS (Dedos formando um círculo)", ["letra o", "libras o", "zero libras"]),
17: ("CM - 017: Base para Letra H (Indicador e médio estendidos, polegar lateral)", ["base h"]),

# ==========================================

# BLOCO 1.1: ESTÁTICOS COM MOV. DE DEDOS -> 18 a 20

# ==========================================

18: ("CM - 018: Sinal de Água (Indicador batendo repetidas vezes)", ["agua", "água", "sede", "beber"]),
19: ("CM - 019: Sinal de Aspas (Indicador e médio dobrando repetidas vezes)", ["aspas", "citação", "quote", "entre aspas"]),
20: ("CM - 105: Todos os dedos com oscilação (Aceno)", ["aceno", "acenar", "tchau", "oi", "olá", "ola", "hello", "wave", "saudação", "cumprimentar", "e ai", "e aí"]),
# 20: ("CM - 020: Reservado para futuros", ["reservado"]),

# 22: ("CM - 117: Letra H em LIBRAS (Base do H com rotação do pulso)", ["letra h", "libras h"]),

# ==========================================

# BLOCO 2: DINÂMICOS (Com oscilação do pulso) -> 100 a 120

# ==========================================

# 100: ("CM - 100: Mão totalmente fechada com oscilação", ["bater", "soco", "bater na porta"]),

# 101: ("CM - 101: Dedo indicador com oscilação (Sinal de Não)", ["nao", "não", "negativo", "recusa", "discordo", "rejeitar"]),

# 102: ("CM - 102: Indicador e médio com oscilação", ["observar", "olhar"]),

# 103: ("CM - 103: Indicador, médio e anelar com oscilação", ["tres balançando"]),

# 104: ("CM - 104: Indicador, médio, anelar e mindinho com oscilação", ["quatro balançando"]), # 106: ("CM - 106: Polegar, indicador e mindinho com oscilação", ["te amo balançando", "ily com movimento"]),

# 107: ("CM - 107: Polegar com oscilação", ["joinha balançando", "positivo balançando"]),

# 108: ("CM - 108: Dedo médio com oscilação", ["médio balançando"]),

# 109: ("CM - 109: Polegar e mindinho com oscilação", ["shaka balançando", "telefone balançando"]),

# 110: ("CM - 110: Indicador e mindinho com oscilação", ["rock balançando"]),

# 111: ("CM - 111: Mindinho com oscilação", ["mindinho balançando"]),

# 112: ("CM - 112: Polegar e indicador com oscilação", ["letra l balançando"]), # 113: ("CM - 113: Médio, anelar e mindinho com oscilação", ["ok balançando"]),

# 114: ("CM - 114: Letra C com oscilação do pulso", ["c balançando"]),

# 115: ("CM - 115: Letra A com oscilação do pulso", ["a balançando"]),

# 116: ("CM - 116: Letra O com oscilação do pulso", ["o balançando"]),

# 118: ("CM - 118: Sinal de Água com oscilação do pulso", ["agua balançando"]), # 119: ("CM - 119: Sinal de Aspas com oscilação do pulso", ["aspas balançando"]), # 120: ("CM - 120: Reservado com oscilação", ["reservado balançando"]),

}

LLM_MODEL = "llama3.1"

# Bloco de texto que descreve os gestos, reutilizado no prompt do LLM _GESTOS_PROMPT = "\n".join(

f" ID {gid}: {desc}" for gid, (desc, _) in GESTOS.items()
)

_PROMPT_TEMPLATE = """\
Você é o controlador de uma mão robótica de LIBRAS.
Sua tarefa: dada a frase do usuário, escolher O ÚNICO gesto da lista abaixo
que melhor representa o que a frase quer dizer.
REGRA EXTRA: Se o usuário pedir o resultado de uma soma ou subtração simples, resolva a conta matematicamente. Se o resultado for de 0 a 5, retorne o ID correspondente ao resultado numérico.

Sua ÚNICA saída permitida é uma destas duas formas:
- "GESTO: <ID>" (usando um ID que EXISTE na lista abaixo)
- "NENHUM" | (quando nada na lista se encaixa na frase, ou se o resultado da conta for menor
que 0 ou maior que 5)
PROIBIDO escrever qualquer outra coisa, explicação ou texto extra.

GESTOS DISPONÍVEIS (ID: Descrição):
{gestos}

EXEMPLOS (siga exatamente este formato): Entrada: "Oi"
Saída: GESTO: 105

Entrada: "Quanto é 1 + 1?"
Saída: GESTO: 2

Entrada: "3 - 3"
Saída: GESTO: 0

Entrada: "soma 2 mais 3"
Saída: GESTO: 5

Entrada: "Tchau, até mais" Saída: GESTO: 105

Entrada: "Abre a mão"
Saída: GESTO: 5

Entrada: "Fecha a mão"
Saída: GESTO: 0

Entrada: "Manda um joinha" Saída: GESTO: 7

Entrada: "Te amo"
Saída: GESTO: 6

Entrada: "Faz o sinal de paz" Saída: GESTO: 2

Entrada: "Não"
Saída: GESTO: 101

Entrada: "asdfghjkl"
Saída: NENHUM

Entrada: "5 + 5"
Saída: NENHUM

Entrada: "{texto}"
Saída: """

class MapeadorDeSinais:
def __init__(self, llm_model: str = LLM_MODEL):

self.llm_model = llm_model
logger.info(f"MapeadorDeSinais iniciado com modelo '{self.llm_model}'.")

async def _classificar_com_llm(self, texto: str) -> Optional[int]:
prompt = _PROMPT_TEMPLATE.format(gestos=_GESTOS_PROMPT, texto=texto) try:
client = ollama.AsyncClient()
response = await client.generate(
model=self.llm_model,
prompt=prompt,
options={
"temperature": 0.0,
"top_p": 0.1,
"num_predict": 10, # basta pra "GESTO: NNN" ou "NENHUM" },
)

raw = response["response"].strip().upper()
logger.info(f"LLM bruto: '{raw}'")

# O modelo explicitamente não encontrou gesto if "NENHUM" in raw:

return None

# Extrai o ID e valida contra a tabela real match = re.search(r"GESTO:\s*(\d+)", raw)

if match:
gid = int(match.group(1))
if gid in GESTOS: | # <- aceita a biblioteca inteira (0-20, 100-120)
return gid
logger.warning(f"LLM retornou ID {gid} fora da tabela GESTOS.")

except Exception as e:
logger.error(f"Erro ao chamar LLM: {e}")
return None

def _classificar_por_keywords(self, texto: str) -> Optional[int]: """Fallback por palavras-chave (correspondência por palavra inteira).""" texto_lower = texto.lower()
for gid, (_, keywords) in GESTOS.items():
for kw in keywords:
# Ignora keywords de 1 caractere: "i", "a", "o" casariam dentro # de qualquer palavra ("oi", "a mão") e geram falsos positivos. if len(kw) < 2:

continue
# \b garante palavra/expressão inteira, não substring solta. if re.search(rf"\b{re.escape(kw)}\b", texto_lower): logger.info(f"Keyword '{kw}' → gesto {gid}")

return gid
return None

async def processar_comando(self, texto_usuario: str) -> Tuple[Optional[list], Optional[str], float]:
"""
Retorna (lista_de_ids, descricao, confianca).
A lista sempre tem no máximo 1 gesto (1 sinal por frase). """
if not texto_usuario or not texto_usuario.strip(): return None, None, 0.0

texto = texto_usuario.strip()

# Estágio 1: LLM

gid = await self._classificar_com_llm(texto) if gid is not None:
desc = GESTOS[gid][0]
logger.info(f"LLM → gesto {gid}: '{desc}'")
return [gid], desc, 1.0

# Estágio 2: fallback por palavras-chave

logger.warning("LLM não retornou gesto. Tentando fallback por keywords.") gid_fallback = self._classificar_por_keywords(texto)
if gid_fallback is not None:
desc = GESTOS[gid_fallback][0]
return [gid_fallback], desc, 0.75 logger.warning(f"Nenhum gesto reconhecido para: '{texto}'") return None, None, 0.0

Arquivo: backend/bluetooth_sender.py.

from bleak import BleakClient
import asyncio

MAC_ADDRESS = "b4:3a:45:b4:48:11"
UUID_COMANDO = "19b10001-e8f2-537e-4f6c-d104768a1214" ble_client = None

# Mude para False quando for testar com o Arduino físico!

MOCK_BLE = False

async def conectar_bluetooth():
"""Função chamada quando o servidor liga para abrir a conexão.""" global ble_client

if MOCK_BLE:
print("SIMULAÇÃO ATIVA: Fingindo conexão com o Arduino (Mock Mode).") return

print(f"Tentando conectar ao MAO-BOT em {MAC_ADDRESS}...")
ble_client = BleakClient(MAC_ADDRESS)
try:
await ble_client.connect()
if ble_client.is_connected:
print("Conectado ao MAO-BOT com sucesso! Mantendo conexão ativa.") except Exception as e:
print(f"Aviso: Não foi possível conectar na inicialização. Erro: {e}")

async def desconectar_bluetooth():
"""Função chamada quando o servidor desliga para liberar o rádio do PC.""" global ble_client
if MOCK_BLE:
return
if ble_client and ble_client.is_connected: await ble_client.disconnect()
print("Desconectado do MAO-BOT.")

async def enviar_comando_bluetooth(comando: int):
"""Função que o server.py chama para enviar o número do gesto.""" global ble_client

if MOCK_BLE:
print(f"SIMULAÇÃO: Comando {comando} transmitido para a mão!") return True

# Sistema de Autocura (Auto-reconnect)

if not ble_client or not ble_client.is_connected: print("Bluetooth offline. Tentando reconectar agora...") try:
if not ble_client:
ble_client = BleakClient(MAC_ADDRESS)
await ble_client.connect() print("Reconexão bem-sucedida!")
except Exception as e:
print(f"Falha na reconexão: {e}")
return False # Retorna falso para o server.py saber que falhou

# Transmissão do Comando

try:
await ble_client.write_gatt_char(UUID_COMANDO, bytearray([comando])) print(f"Comando {comando} transmitido!")
return True
except Exception as e:
print(f"Falha na transmissão: {e}") return False

Arquivo: backend/requirements.txt.

annotated-doc==0.0.4
annotated-types==0.7.0

anyio==4.14.1
bleak==3.0.2
certifi==2026.6.17
click==8.4.2
dbus-fast==5.0.22
fastapi==0.138.1
h11==0.16.0
httpcore==1.0.9
httpx==0.28.1
idna==3.18
Levenshtein==0.27.3
ollama==0.6.2
pydantic==2.13.4
pydantic_core==2.46.4
python-Levenshtein==0.27.3 RapidFuzz==3.14.5
starlette==1.3.1
thefuzz==0.22.1
typing-inspection==0.4.2
typing_extensions==4.15.0
uvicorn==0.49.0

## APÊNDICE C – FIRMWARE EMBARCADO (C++)

Hardware de destino: Arduino Uno R4 WiFi. Firmware principal (BLE + servos). Arquivo: arduino/mao_robotica/mao_robotica.ino.

#include <ArduinoBLE.h>

#include <Servo.h>

// --- Configuração do Bluetooth (BLE) ---
BLEService maoService("19b10000-e8f2-537e-4f6c-d104768a1214");
BLEByteCharacteristic comandoCharacteristic("19b10001-e8f2-537e-4f6c-d104768a1214", BLERead | BLEWrite);

// --- Configuração dos Servomotores ---
Servo mindinho;
Servo anelar;
Servo meio;
Servo indicador;
Servo polegar;
Servo pulso;

void setup()
{
Serial.begin(9600);

// Opcional: Aguarda o monitor serial abrir para debugar // while (!Serial);

// Anexando os servos aos pinos digitais do Arduino pulso.attach(7);
mindinho.attach(8);
anelar.attach(9);
meio.attach(10);
indicador.attach(11);
polegar.attach(12);

// Começa com a mão aberta abrirMao();

// --- Inicialização do BLE ---
if (!BLE.begin())
{
Serial.println("Falha ao iniciar o Bluetooth!"); while (1)
;
}

BLE.setLocalName("MaoRobotica"); BLE.setAdvertisedService(maoService);

maoService.addCharacteristic(comandoCharacteristic); BLE.addService(maoService);

// Valor inicial da característica comandoCharacteristic.writeValue(5); // Começa no 5 (Mão aberta) Serial.print("Endereço MAC atual: "); Serial.println(BLE.address());
BLE.advertise();
Serial.println("Bluetooth ativo! Aguardando o backend conectar..."); }

void loop()
{
// Fica escutando se o backend se conectou BLEDevice central = BLE.central();

if (central)
{
Serial.print("Backend conectado! Endereço MAC: "); Serial.println(central.address());

// Enquanto o backend estiver conectado
while (central.connected())
{

// Verifica se o backend Python enviou um novo gesto if (comandoCharacteristic.written())
{

byte comandoRecebido = comandoCharacteristic.value();

Serial.print("Comando recebido do backend: "); Serial.println(comandoRecebido);

// Repassa o número recebido para a sua função de controle dos servos executarComando(comandoRecebido);
}

// Pequeno atraso para manter a estabilidade da conexão de rádio BLE delay(10);
}

Serial.print("Backend desconectado: "); Serial.println(central.address()); Serial.println("Aguardando nova conexão..."); }
}

// ==========================================
// FUNÇÕES DE CONTROLE DOS MOTORES (LIBRAS)
// ==========================================

void executarComando(byte comando) {
// O comando 120 cabe num 'byte' sem problemas (limite é 255) byte base = comando % 100;
bool oscilar = comando >= 100;

Serial.print("Executando base: ");
Serial.print(base);
Serial.print(" | Oscilar pulso: ");
Serial.println(oscilar ? "SIM" : "NAO");

// 1. Resolve a configuração física dos dedos
if (base <= 17) {
configurarDedos(base);
delay(500); // Tempo para os motores estáticos chegarem na posição } else if (base == 18) {
libras_agua();
} else if (base == 19) {
aspas();
} else if(base == 20) {
configurarDedos(5);
oscilarPulso();
}
// delay(1200); | // Aguarda um tempo de leitura confortável

// // 2. Resolve o movimento do pulso
// if (oscilar) {
// oscilarPulso();
// } else {
// | pulso.write(100); // Fixa o pulso na posição de descanso
// | delay(1500); | // Aguarda um tempo de leitura confortável
// }
delay(800); | // Aguarda um tempo de leitura confortável
// 3. Ao finalizar a ação, volta à posição de descanso abrirMao();
}

void configurarDedos(byte base) {
// ESTADO PADRÃO: MÃO TOTALMENTE FECHADA (Comando 0) // ---
// Lógica Invertida (Hardware):
// Mindinho, Anelar, Meio -> Fechado = 180 | Aberto = 0
// Indicador -> Fechado = 0 | Aberto = 180
// ---
int min = 180;
int ane = 180;
int mei = 180;
int ind = 0;
int pol = 0;

// Muta os ângulos apenas para os dedos que precisam abrir/dobrar switch (base) {
case 1: ind = 180; break; // Indicador
case 2: ind = 180; mei = 0; break; // Paz
case 3: ind = 180; mei = 0; ane = 0; break; // Três
case 4: ind = 180; mei = 0; ane = 0; min = 0; break; // Quatro
case 5: ind = 180; mei = 0; ane = 0; min = 0; pol = 180; break; // Cinco / Mão Aberta case 6: ind = 180; min = 0; pol = 180; break; // Eu te amo
case 7: pol = 180; break; // Joinha
case 8: mei = 0; break; // Dedo do meio
case 9: min = 0; pol = 180; break; // Shaka
case 10: ind = 180; min = 0; break; // Rock
case 11: min = 0; break; // Letra I
case 12: ind = 180; pol = 180; break; // Letra L
case 13: mei = 0; ane = 0; min = 0; break; // OK (Pol e Ind fechados, tocando) case 14: min = 80; ane = 100; mei = 140; ind = 70; pol = 120; break; // Letra C case 15: pol = 80; break; // Letra A (Punho fechado, polegar relaxado na lateral) case 16: min = 100; ane = 120; mei = 150; ind = 0; pol = 25; break; // Letra O case 17: mei = 0; ind = 180; pol = 80; break; // Base H
}

// Envia todos os comandos de uma vez
mindinho.write(min);
anelar.write(ane);
meio.write(mei);
indicador.write(ind);
polegar.write(pol);
}
void abrirMao() {
configurarDedos(5); // CM-005 é a mão espalmada pulso.write(100);
}

void moverSuave(Servo &s, int alvo, int passo, int atraso) {
int atual = s.read(); | // ultimo angulo comandado
// Exibe "Atual: " e depois o valor da variável //Serial.print("Atual: ");
//Serial.println(atual);

// Exibe "Alvo: " e depois o valor da variável //Serial.print("Alvo: ");
//Serial.println(alvo);

if (atual < alvo) {
for (int a = atual; a <= alvo; a += passo) { s.write(a); delay(atraso); } } else {
for (int a = atual; a >= alvo; a -= passo) { s.write(a); delay(atraso); } }
s.write(alvo);
}

void oscilarPulso() {
for (int i = 0; i < 2; i++) {
moverSuave(pulso, 0, 2, 10); | // sobe suave
moverSuave(pulso, 160, 2, 10); | // desce suave
}
}

// ==========================================
// MOVIMENTOS COM REPETIÇÃO NOS DEDOS
// ==========================================

void libras_agua() {
mindinho.write(180);
anelar.write(180);
meio.write(180);
polegar.write(180);
pulso.write(100);
delay(300);

// Indicador batendo repetidas vezes for (int i = 0; i < 4; i++) { indicador.write(0);
delay(600);
indicador.write(180);
delay(600);

} }

void aspas() {
mindinho.write(180);
anelar.write(180);
polegar.write(0);
pulso.write(100);

// Médio e Indicador dobram ao mesmo tempo for(int i = 0; i < 2; i++) {
meio.write(0); | // Aberto
indicador.write(180); // Aberto delay(700);
meio.write(180); | // Fechado
indicador.write(0); | // Fechado
delay(1000);
}
meio.write(0); | // Aberto
indicador.write(180); }

## APÊNDICE D – FIRMWARE DE TESTES POR SERIAL (C++)

## Hardware de destino: Arduino Uno R4 WiFi. Firmware auxiliar para testes via

Monitor Serial. Arquivo: arduino/sinais_mao_robotica.ino.

#include <Servo.h>

Servo mindinho;
Servo anelar;
Servo meio;
Servo indicador;
Servo polegar;
Servo pulso;

void setup() {
Serial.begin(9600);

mindinho.attach(8);
anelar.attach(9);
meio.attach(10);
indicador.attach(11);
polegar.attach(12);
pulso.attach(7);

// Começa com a mão aberta
abrirMao();

Serial.println("Digite um numero de 0 a 10:"); Serial.println("0 = Mao fechada"); Serial.println("1 = Um");
Serial.println("2 = Dois");
Serial.println("3 = Tres"); Serial.println("4 = Quatro"); Serial.println("5 = Cinco / Mao aberta"); Serial.println("6 = Eu te amo"); Serial.println("7 = Joia"); Serial.println("8 = Dedo meio"); Serial.println("9 = Surfista"); Serial.println("10 = Rock"); Serial.println("11 = Aceno"); Serial.println("12 = I em Libras"); Serial.println("13 = L em Libras"); Serial.println("14 = ok"); Serial.println("15 = nao"); Serial.println("16 = agua"); Serial.println("17 = Aspas"); Serial.println("18 = C em Libras"); Serial.println("19 = H em Libras"); Serial.println("20 = A em Libras"); Serial.println("21 = O em Libras");

}

void loop() {
if (Serial.available() > 0) {
int comando = Serial.parseInt();

// Limpa o restante do buffer do Serial while (Serial.available() > 0) { Serial.read();
}

executarComando(comando);
}
}

void executarComando(int comando) { switch (comando) {
case 0:
fecharMao();
Serial.println("Mao fechada"); break;

case 1:
um();

Serial.println("Um");
break;

case 2:
dois();
Serial.println("Dois");
break;

case 3:
tres();
Serial.println("Tres");
break;

case 4:
quatro();
Serial.println("Quatro");
break;

case 5:
cinco();
Serial.println("Cinco ou Mao Aberta"); break;

case 6:
eu_te_amo();
Serial.println("Eu Te Amo"); break;

case 7:
joia();
Serial.println("Joia");
break;

case 8:
dedo_meio();
Serial.println("Xingamento"); break;

case 9:
surfista();
Serial.println("Surfista"); break;

case 10:
rock();
Serial.println("Rock");
break;

case 11:
aceno();
Serial.println("Aceno");
break;

case 12:
libras_I();
Serial.println("I em Libras"); break;

case 13:
libras_L();
Serial.println("L em Libras"); break;

case 14:
ok();
Serial.println("ok");
break;

case 15:
nao();
Serial.println("nao");
break;

case 16:
libras_agua();
Serial.println("agua");
break;

case 17:
aspas();
Serial.println("Aspas");
break;

case 18:
libras_C();
Serial.println("C em Libras"); break;

case 19:
libras_H();
Serial.println("H em Libras"); break;

case 20:
libras_A();
Serial.println("A em Libras"); break;

case 21:
libras_O();
Serial.println("O em Libras"); break;

default:
erro();
Serial.println("Comando invalido. Digite um numero de 0 a 21."); break;
}
}

// Função para abrir a mão void abrirMao() {
cinco();
}

// Função para fechar a mão void fecharMao() {
mindinho.write(180);
anelar.write(180);
meio.write(180);
indicador.write(0);
polegar.write(0);
// pulso.write(100);

delay(5000);
abrirMao();
}

void um() {
mindinho.write(180);
anelar.write(180);
meio.write(180);
indicador.write(180);
polegar.write(0);
// pulso.write(100);

delay(2000);
abrirMao();
}

void dois() {
mindinho.write(180);
anelar.write(180);
meio.write(0);
indicador.write(180);
polegar.write(0);
// pulso.write(100);

delay(2000);
abrirMao();
}

void tres() {
mindinho.write(180);

anelar.write(0);
meio.write(0);
indicador.write(180);
polegar.write(0);
// pulso.write(100);

delay(2000);
abrirMao(); }

void quatro() {
mindinho.write(0);
anelar.write(0);
meio.write(0);
indicador.write(180);
polegar.write(0);
// pulso.write(100);

delay(2000);
abrirMao(); }

void cinco() {
mindinho.write(0);
anelar.write(0);
meio.write(0);
indicador.write(180);
polegar.write(180);
pulso.write(140);

delay(2000); }

void eu_te_amo() {
mindinho.write(0);
anelar.write(180);
meio.write(180);
indicador.write(180);
polegar.write(180);
// pulso.write(100);

delay(2000);
abrirMao(); }

void joia() {
mindinho.write(180);
anelar.write(180);
meio.write(180);
indicador.write(0);
polegar.write(180);
// pulso.write(100);

delay(2000);
abrirMao(); }

void dedo_meio() {
mindinho.write(180);
anelar.write(180);
meio.write(0);
indicador.write(0);
polegar.write(0);
// pulso.write(100);

delay(2000);
abrirMao(); }

void surfista() {
mindinho.write(0);
anelar.write(180);
meio.write(180);
indicador.write(0);
polegar.write(180);
delay(300);
for (int i = 0; i < 3; i++) {

pulso.write(30);
delay(400);
pulso.write(180);
delay(400);
}

delay(2000);
abrirMao(); }

void rock() {
mindinho.write(0);
anelar.write(180);
meio.write(180);
indicador.write(180);
polegar.write(0);
// pulso.write(100);

delay(2000);
abrirMao(); }

void aceno() {
// Mão aberta, pulso oscila 4 vezes abrirMao();
delay(300);
for (int i = 0; i < 4; i++) { pulso.write(30);
delay(400);
pulso.write(180);
delay(400);
}

delay(2000);
abrirMao(); }

void libras_I() {
mindinho.write(0);
anelar.write(180);
meio.write(180);
indicador.write(0);
polegar.write(0);

delay(2000);
abrirMao(); }

void libras_L() {
mindinho.write(180);
anelar.write(180);
meio.write(180);
indicador.write(180);
polegar.write(180);

delay(2000);
abrirMao(); }

void ok() {
mindinho.write(0);
anelar.write(0);
meio.write(0);
indicador.write(0);
polegar.write(0);

delay(2000);
abrirMao(); }

void nao() {
mindinho.write(180);
anelar.write(180);
meio.write(180);
indicador.write(180);
polegar.write(0);
delay(300);

for (int i = 0; i < 3; i++) { pulso.write(30);
delay(400);
pulso.write(180);
delay(400);
}

delay(2000);
abrirMao(); }

void libras_agua() {
mindinho.write(180);
anelar.write(180);
meio.write(180);
polegar.write(180);
delay(300);
// indicador bate repetidas vezes for (int i = 0; i < 4; i++) { indicador.write(0);
delay(700);
indicador.write(180);
delay(700);
}

delay(2000);
abrirMao(); }

void aspas() {
mindinho.write(180);
anelar.write(180);
meio.write(0);
indicador.write(180);
polegar.write(0);
pulso.write(120);
delay(1200);
meio.write(180);
indicador.write(0);
delay(1200);
meio.write(0);
indicador.write(180);
delay(1200);
meio.write(180);
indicador.write(0);
delay(1200);
meio.write(0);
indicador.write(180);
delay(2000);
abrirMao(); }

void libras_C() {
mindinho.write(80);
anelar.write(100);
meio.write(140);
indicador.write(70);
polegar.write(120);
delay(2000);
abrirMao(); }

void libras_H() {
mindinho.write(180);
anelar.write(180);
meio.write(0);
indicador.write(180);
polegar.write(80);
delay(1200);
pulso.write(50);
delay(1600);
Serial.println("Chegeui aqui no H"); pulso.write(180);
delay(2000);
Serial.println("Chegeui aqui 2 no H"); abrirMao(); }

void libras_A() {
mindinho.write(180);
anelar.write(180);
meio.write(0);
indicador.write(180);
polegar.write(80);
delay(2000);
abrirMao(); }

void libras_O() {
mindinho.write(100);
anelar.write(120);
meio.write(150);
indicador.write(0);
polegar.write(25);

delay(2000);
abrirMao(); }

void erro(){
// Tremor da mao
for (int i = 0; i < 8; i++) {

pulso.write(80);
delay(300);

if(i == 0){
indicador.write(0);
delay(100);
}else if(i == 1){
indicador.write(180);
meio.write(180);
delay(100);
}else if(i == 2){
meio.write(0);
anelar.write(180);
delay(100);
}else if(i == 3){
anelar.write(0);
mindinho.write(180);
delay(100);
}else if(i == 4){
mindinho.write(0);
polegar.write(0);
delay(100);
}else if(i == 5){
polegar.write(180);
delay(100);
}else if(i == 6){
polegar.write(50);
delay(100);
}else if(i == 7){
mindinho.write(50);
delay(100);
}
pulso.write(145);
delay(300);
}

delay(2000);
// Volta ao normal
abrirMao(); }

## APÊNDICE E – PROTÓTIPO INICIAL DO SERVIDOR (FLASK)

## Hardware de destino: computador (PC/notebook). Primeira versão do servidor

(Flask + Ollama), mantida como referência histórica. Arquivo: server/app.py.

"""
Servidor Flask do projeto FalaComaMão (LIBRAS-BOT).

Etapa 1 — orquestração entre Flutter e Ollama:

Flutter (texto NLP) ──HTTP──> /api/comando ──> Ollama ──> sinal escolhido │
└──> (etapa 4) BLE → Arduino

Endpoints:
GET /api/status | — saúde do servidor + Ollama
GET /api/sinais | — lista todos os sinais cadastrados
POST /api/sinais | — cadastra um novo sinal
DELETE /api/sinais/<id> | — remove um sinal pelo id
POST /api/comando | — recebe texto e devolve qual sinal o Ollama escolheu
"""

from __future__ import annotations

import json
import logging
import re
import threading
from pathlib import Path
from typing import Any

from flask import Flask, abort, jsonify, request
from flask_cors import CORS

from ollama_client import OllamaError, classificar_intencao, healthcheck

logging.basicConfig(
level=logging.INFO,
format="%(asctime)s [%(levelname)s] %(name)s: %(message)s",
)
log = logging.getLogger("falacomamao")

SIGNS_FILE = Path(__file__).parent / "signs.json"
_signs_lock = threading.Lock() # protege leitura/escrita concorrente do JSON

DEDOS = ("polegar", "indicador", "medio", "anelar", "minimo")
SERVOS = (*DEDOS, "pulso")
ID_REGEX = re.compile(r"^[a-z0-9_\-]{1,40}$")

app = Flask(__name__)
CORS(app) # permite chamadas do Flutter Web; em mobile é inofensivo.

# ---------------------------------------------------------------------------# Persistência (JSON file)

def carregar_sinais() -> list[dict]:
with _signs_lock:
if not SIGNS_FILE.exists():
return []
with open(SIGNS_FILE, "r", encoding="utf-8") as f: data = json.load(f)
return data.get("sinais", [])

def salvar_sinais(sinais: list[dict]) -> None:
with _signs_lock:
with open(SIGNS_FILE, "w", encoding="utf-8") as f: json.dump({"sinais": sinais}, f, ensure_ascii=False, indent=2)

# ---------------------------------------------------------------------------# Validação

def _validar_sinal(payload: Any) -> dict:
"""
Valida o payload de um novo sinal e devolve o dict normalizado. Levanta `ValueError` com mensagem amigável se algo estiver errado.
"""
if not isinstance(payload, dict):
raise ValueError("Esperado um objeto JSON com os campos do sinal.")

sid = str(payload.get("id", "")).strip().lower()
nome = str(payload.get("nome", "")).strip()
descricao = str(payload.get("descricao", "")).strip()
sinonimos = payload.get("sinonimos", []) angulos_raw = payload.get("angulos", {})

if not sid or not ID_REGEX.match(sid):
raise ValueError(
"Campo 'id' inválido. Use minúsculas, números, hífen ou underscore (1-40 caracteres)." )
if not nome:
raise ValueError("Campo 'nome' é obrigatório.")
if not descricao:
raise ValueError("Campo 'descricao' é obrigatório (o Ollama usa pra decidir).") if not isinstance(sinonimos, list) or not all(isinstance(x, str) for x in sinonimos): raise ValueError("Campo 'sinonimos' deve ser uma lista de strings.")
if not isinstance(angulos_raw, dict):
raise ValueError("Campo 'angulos' deve ser um objeto com os 6 servos.")

angulos: dict[str, int] = {}
for servo in SERVOS:
if servo not in angulos_raw:
raise ValueError(f"Faltando ângulo do servo '{servo}'.") try:
valor = int(angulos_raw[servo])
except (TypeError, ValueError) as e:
raise ValueError(f"Ângulo de '{servo}' precisa ser inteiro.") from e if not 0 <= valor <= 180:
raise ValueError(f"Ângulo de '{servo}' fora do intervalo 0..180.") angulos[servo] = valor

return {
"id": sid,
"nome": nome,
"descricao": descricao,
"sinonimos": [s.strip() for s in sinonimos if s.strip()], "angulos": angulos,
}

# ---------------------------------------------------------------------------# Endpoints

@app.route("/api/status", methods=["GET"])
def status():
ollama = healthcheck()
sinais = carregar_sinais()
return jsonify({
"servidor": "online",
"sinais_cadastrados": len(sinais), "ollama": ollama,
})

@app.route("/api/sinais", methods=["GET"])
def listar_sinais():
return jsonify({"sinais": carregar_sinais()})

@app.route("/api/sinais", methods=["POST"])
def cadastrar_sinal():
try:
novo = _validar_sinal(request.get_json(silent=True)) except ValueError as e:
return jsonify({"erro": str(e)}), 400

sinais = carregar_sinais()

if any(s["id"] == novo["id"] for s in sinais):
return jsonify({"erro": f"Já existe um sinal com id '{novo['id']}'."}), 409

sinais.append(novo)
salvar_sinais(sinais)
log.info("Sinal cadastrado: %s", novo["id"])
return jsonify({"ok": True, "sinal": novo}), 201

@app.route("/api/sinais/<sinal_id>", methods=["DELETE"]) def remover_sinal(sinal_id: str):
sid = sinal_id.strip().lower()
sinais = carregar_sinais()
novos = [s for s in sinais if s["id"] != sid]
if len(novos) == len(sinais):
abort(404, description=f"Sinal '{sid}' não encontrado.") salvar_sinais(novos)
log.info("Sinal removido: %s", sid)
return jsonify({"ok": True, "id": sid})

@app.route("/api/comando", methods=["POST"])
def comando():
"""
Recebe o texto do Flutter (form-urlencoded `comando=...` OU JSON `{"comando": ...}`), pergunta pro Ollama qual sinal usar e devolve o sinal + ângulos.
"""
texto = (
request.form.get("comando")
or (request.get_json(silent=True) or {}).get("comando") or ""
).strip()

if not texto:
return jsonify({"erro": "Campo 'comando' vazio."}), 400

sinais = carregar_sinais()
if not sinais:
return jsonify({
"erro": "Nenhum sinal cadastrado. Cadastre sinais em /api/sinais antes." }), 409

try:
escolhido = classificar_intencao(texto, sinais)
except OllamaError as e:
log.exception("Falha no Ollama")
return jsonify({"erro": str(e)}), 502

if escolhido is None:
return jsonify({
"texto": texto,
"sinal": None,
"mensagem": "Nenhum sinal cadastrado corresponde ao que você falou.", })

# TODO etapa 4: enviar `escolhido["angulos"]` para o Arduino via BLE. return jsonify({

"texto": texto,
"sinal": escolhido,
"mensagem": f"Executando sinal: {escolhido['nome']}", })

@app.errorhandler(404)
def _404(e):
return jsonify({"erro": str(e.description) if hasattr(e, "description") else "Não encontrado"}), 404

if __name__ == "__main__":
# host=0.0.0.0 → o Flutter no celular acessa pelo IP do PC na mesma rede. app.run(host="0.0.0.0", port=5000, debug=True)

Arquivo: server/ollama_client.py.

"""
Cliente Ollama para o projeto FalaComaMão (LIBRAS-BOT).

Recebe uma fala/texto em português e a lista de sinais cadastrados, e devolve qual sinal melhor representa a intenção do usuário.

A API do Ollama roda localmente em http://localhost:11434.
Usamos `format=json` + `temperature=0.1` para forçar saída estruturada e determinística — ideal para classificação de intenção.
"""

from __future__ import annotations

import json
import logging
from typing import Optional

import requests

logger = logging.getLogger(__name__)

OLLAMA_URL = "http://localhost:11434/api/generate" MODEL = "llama3.1:8b"
TIMEOUT_SEGUNDOS = 60

class OllamaError(Exception):
"""Erro genérico ao falar com o Ollama (offline, modelo ausente, JSON inválido, etc.)."""

def _formatar_lista_sinais(sinais: list[dict]) -> str:
"""Monta a descrição dos sinais disponíveis para o LLM."""
linhas = []
for s in sinais:
sinonimos = ", ".join(s.get("sinonimos", [])) or "(sem sinônimos)" linhas.append(
f'- id: "{s["id"]}"\n'
f' nome: {s["nome"]}\n'
f' quando usar: {s["descricao"]}\n' f' sinônimos/contextos: {sinonimos}' )
return "\n".join(linhas)

def _montar_prompt(texto_usuario: str, sinais: list[dict]) -> str: """Prompt de classificação de intenção em PT-BR."""
lista = _formatar_lista_sinais(sinais)
return (
"Você é um classificador de intenções para uma mão robótica que executa sinais (gestos). \n"
"Sua tarefa: dada uma fala/texto do usuário em português, escolha QUAL DOS SINAIS abaixo " "melhor representa a intenção dele.\n\n"
"SINAIS DISPONÍVEIS:\n"
f"{lista}\n\n"
"REGRAS:\n"
'- Responda APENAS em JSON válido com o formato: {"sinal": "id_do_sinal"}.\n'
'- Se NENHUM sinal se aplicar, responda: {"sinal": "nenhum"}.\n'
"- O campo \"sinal\" deve conter EXATAMENTE um dos ids listados acima, ou \"nenhum\".\n" "- Não inclua explicações, comentários ou texto fora do JSON.\n\n"
f'FALA DO USUÁRIO: "{texto_usuario}"\n\n'
"JSON:"
)

def classificar_intencao(
texto_usuario: str,
sinais: list[dict],
*,
model: str = MODEL,
url: str = OLLAMA_URL,
timeout: int = TIMEOUT_SEGUNDOS,
) -> Optional[dict]:
"""
Classifica o texto do usuário e devolve o dicionário do sinal escolhido (com `id`, `nome`, `angulos`, ...), ou `None` se nenhum sinal corresponder.

Levanta `OllamaError` se a chamada falhar ou se a resposta for inválida.

"""
if not texto_usuario or not texto_usuario.strip():
return None
if not sinais:
logger.warning("Nenhum sinal cadastrado — Ollama não tem o que escolher.") return None

prompt = _montar_prompt(texto_usuario.strip(), sinais)

payload = {
"model": model,
"prompt": prompt,
"stream": False,
"format": "json",
"options": {
"temperature": 0.1,
"top_p": 0.9,
},
}

try:
resp = requests.post(url, json=payload, timeout=timeout) resp.raise_for_status()
except requests.exceptions.ConnectionError as e:
raise OllamaError(
"Não consegui conectar no Ollama em "
f"{url}. O serviço está rodando? (Tente `ollama list` no PowerShell.)" ) from e
except requests.exceptions.Timeout as e:
raise OllamaError(
f"Ollama demorou mais de {timeout}s para responder. "
"Modelo pode estar carregando — tente de novo em alguns segundos."
) from e
except requests.exceptions.HTTPError as e:
raise OllamaError(f"Ollama retornou HTTP {resp.status_code}: {resp.text}") from e

try:
raw = resp.json().get("response", "")
parsed = json.loads(raw)
except (ValueError, KeyError) as e:
raise OllamaError(
f"Resposta do Ollama não veio em JSON válido: {resp.text!r}" ) from e

sinal_id = (parsed.get("sinal") or "").strip().lower() logger.info("Ollama escolheu: %r (texto=%r)", sinal_id, texto_usuario)

if not sinal_id or sinal_id == "nenhum":
return None

for s in sinais:
if s["id"].lower() == sinal_id:
return s

# O modelo respondeu um id que não existe no signs.json — trata como nenhum. logger.warning(

"Ollama retornou id desconhecido %r (sinais disponíveis: %s)", sinal_id,
[s["id"] for s in sinais],
)
return None

def healthcheck(*, url: str = OLLAMA_URL.replace("/api/generate", "/api/tags"), model: str = MODEL) -> dict: """
Checa se o Ollama está no ar e se o modelo desejado está instalado. Retorna um dict com `online: bool` e `modelo_instalado: bool`.
"""
info = {"online": False, "modelo_instalado": False, "modelos": []} try:
resp = requests.get(url, timeout=5)
resp.raise_for_status()
info["online"] = True
modelos = [m.get("name", "") for m in resp.json().get("models", [])] info["modelos"] = modelos
info["modelo_instalado"] = any(m.startswith(model) for m in modelos)

except requests.exceptions.RequestException: pass
return info

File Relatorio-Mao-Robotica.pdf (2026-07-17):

# Mão Robótica com Movimentação de Pulso — LIBRAS-BOT / FalaComaMão

Protótipo de mão robótica de baixo custo, com cinco dedos funcionais e rotação de pulso, capaz de reproduzir configurações de mão (CMs) da Língua Brasileira de Sinais (LIBRAS) a partir de comandos de voz ou texto, interpretados por um modelo de linguagem (LLM) local.

Projeto desenvolvido para a disciplina de Projeto Integrado em Computação II (PIC2) do curso de Engenharia de Computação da Universidade Federal do Espírito Santo (UFES).

Status do projeto: Finalizado / funcional.

Repositório público (GitHub): https://github.com/gk27min/Mao-Robotica-com-Movimentacao-de-Pulso

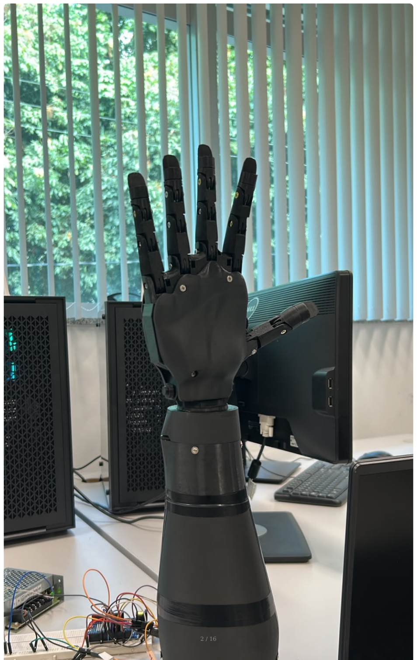
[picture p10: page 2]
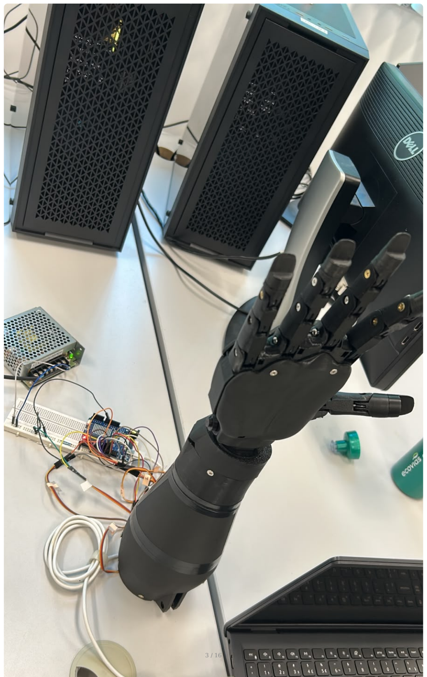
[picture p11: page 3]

Protótipo final montado e a bancada de operação (Arduino Uno R4 WiFi, fonte, protoboard e servidor Python no notebook).

## Índice

Visão geral
Como funciona (fluxo end-to-end) Arquitetura do sistema
O que foi feito
O que foi usado (tecnologias)
Lista de equipamentos e componentes (BOM) Hardware e ligações
Modelos 3D e peças impressas Código-fonte — organização do repositório Guia de recriação (passo a passo) Biblioteca de gestos (CMs)
Dificuldades de desenvolvimento
Vídeos e imagens de demonstração Equipe e créditos

## Visão geral

A FalaComaMão é uma mão robótica antropomórfica impressa em 3D que traduz linguagem natural em gestos de LIBRAS. O usuário fala ou digita uma frase no aplicativo; um LLM rodando localmente interpreta a intenção e a converte em um código de gesto; esse código é enviado por rede até um servidor Python, que o retransmite via Bluetooth Low Energy (BLE) para um Arduino, o qual aciona os seis servomotores para reproduzir a configuração de mão correspondente.

O foco do projeto é acessibilidade e comunicação a um custo muito inferior ao de soluções comerciais, usando exclusivamente hardware aberto, impressão 3D e software livre.

## Como funciona (fluxo end-to-end)

App Flutter (voz/texto) --HTTP/JSON--> Servidor Python (FastAPI) --> LLM local (Ollama / llama3.1) |
v BLE (bytearray[código])
Arduino Uno R4 WiFi --PWM--> 6x Servo MG995 (5 dedos + pulso)

Captura — o app captura a fala (Speech-to-Text nativo) ou o texto digitado.
Interpretação — o servidor Python envia a frase ao Ollama; o LLM escolhe um único gesto da biblioteca e responde no formato GESTO: <ID> . Há um fallback por palavras-chave caso o LLM não responda.
Transmissão — o servidor envia o código do gesto (1 byte) via BLE para o Arduino.
Atuação — o firmware decodifica o byte, resolve os ângulos de cada dedo/pulso e comanda os servomotores. Ao final, a mão retorna à posição de descanso.
Feedback — o app mostra o andamento no chat (Analisando… Mão executando ).

## Arquitetura do sistema

Camada | Tecnologia | Papel
Interface (mobile) | Flutter / Dart | Chat multiplataforma, entrada por voz e texto, biblioteca de gestos
Voz (STT) | speech_to_text (Flutter) | Transcrição de áudio em tempo real
Inteligência | Ollama + llama3.1 (LLM local) | Interpreta a intenção e escolhe o gesto

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
Camada | Tecnologia | Papel
Backend / ponte | Python + FastAPI + Bleak | Orquestra a lógica e faz a ponte BLE com o Arduino
Firmware | C++ (Arduino) + ArduinoBLE + Servo.h | Recebe o código e aciona os servomotores
Hardware | Arduino Uno R4 WiFi + 6× MG995 | Estrutura física impressa em 3D com tração por fio de nylon

## O que foi feito

Aplicativo mobile "FalaComaMão" em Flutter, com duas telas: Conversa (chat com entrada por voz e texto) e Biblioteca (grade com todos os gestos disponíveis, com ícones animados que representam a configuração de cada mão).
Servidor intermediário em Python (FastAPI) que expõe dois endpoints ( /api/comando para linguagem natural e /api/gesto para envio direto de um código) e mantém uma conexão BLE persistente com reconexão automática. Camada de inteligência com Prompt Engineering sobre o Ollama para mapear frases livres em códigos de gesto, incluindo resolução de contas simples (ex.: "1 + 1" gesto de dois dedos) e fallback determinístico por palavras-chave.
Firmware em C++ para o Arduino Uno R4 WiFi, que controla 6 servomotores via PWM, implementa gestos estáticos e gestos dinâmicos (com repetição de dedos e oscilação de pulso) e recebe comandos via BLE. Estrutura física impressa em 3D (PETG), com sistema de tração por fio de nylon e molas de retorno, adaptações de roldanas nos servos e caixa de pulso com rotação.
Biblioteca de ~20 configurações de mão (CMs), espelhada de forma idêntica entre app, backend e firmware (mesmos códigos em toda a stack).

•

•

•

•

•

•

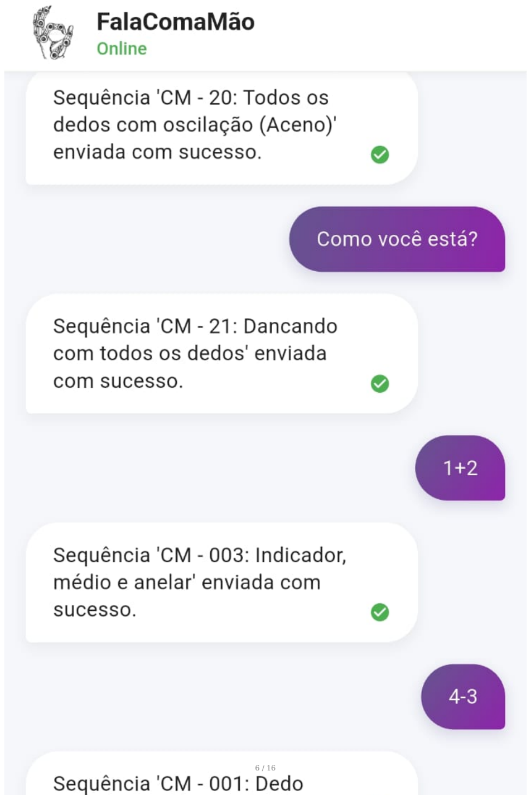
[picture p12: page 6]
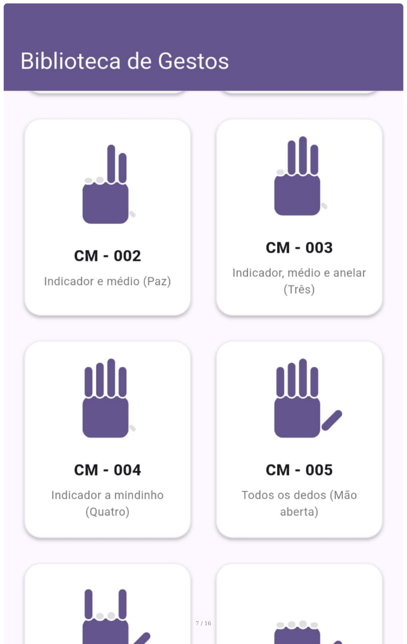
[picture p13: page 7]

App FalaComaMão: tela de conversa (voz/texto) e biblioteca de gestos.

## O que foi usado (tecnologias)

Software

Flutter / Dart — app multiplataforma (Android). Pacotes: speech_to_text (STT) e http .
Python 3.12 — backend. Pacotes principais: fastapi , uvicorn , bleak (BLE), ollama , pydantic (ver backend/ requirements.txt ).
Ollama com o modelo llama3.1 rodando localmente (sem nuvem).
C++ (Arduino IDE) — firmware. Bibliotecas: ArduinoBLE e Servo.h .

Protocolos e comunicação

HTTP/JSON entre app e servidor Python.
Bluetooth Low Energy (BLE / GATT) entre servidor Python e Arduino.

Fabricação

Impressão 3D em filamento PETG.
Tração por fio de nylon, molas de tração sob medida e roldanas adaptadas.

## Lista de equipamentos e componentes (BOM)

### Eletrônica e atuadores

Item | Especificação | Qtd. | Observação
Microcontrolador | Arduino Uno R4 WiFi | 1 | Comunicação por BLE com o servidor Python
Servomotores | MG995 (torque metálico) | 6 | 5 dedos + 1 pulso, controlados por PWM
Fonte de alimentação | Fonte chaveada 5–6 V (corrente suficiente p/ 6 servos) | 1 | Alimenta os servos separadamente do Arduino
Protoboard | Padrão | 1 | Distribuição de alimentação e sinais
Jumpers / cabos | Macho-fêmea e macho-macho | — | Ligações de sinal e alimentação
Cabo USB | USB-C / USB | 1 | Programação e alimentação do Arduino
Smartphone Android | Físico (emulador não recomendado) | 1 | Roda o app; captura de áudio em tempo real
PC / notebook | Roda o servidor Python + Ollama | 1 | Precisa de BLE e estar na mesma rede do celular

Os servomotores devem ser alimentados por uma fonte externa dedicada (não pelos 5 V do Arduino), com GND comum entre a fonte e o Arduino. Seis MG995 sob carga podem exigir picos de corrente que a porta USB não fornece.

### Estrutura mecânica

Item | Especificação | Qtd.
Filamento PETG | Preto | conforme impressão
Fio de nylon | Nylon grosso (~resistência de tração ≈ 50 kg) | rolo
Molas de tração — dedos | ver especificação em Dificuldades | 4
Molas de tração — polegar | ver especificação em Dificuldades | 1
Roldana / polia | 1 impressa sob medida + roldanas de fábrica dos servos | —

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
Item | Especificação | Qtd.
Parafusos | Diversos (fixação das peças) | —

## Hardware e ligações

### Microcontrolador

Arduino Uno R4 WiFi — escolhido pela presença de BLE nativo, o que dispensa módulos externos de Bluetooth e permite receber os comandos diretamente do servidor Python.

### Mapa de pinos (servomotores Arduino)

Servo | Pino digital | Função
Pulso | 7 | Rotação/oscilação do pulso
Mindinho | 8 | Dedo mínimo
Anelar | 9 | Dedo anelar
Médio | 10 | Dedo médio
Indicador | 11 | Dedo indicador
Polegar | 12 | Polegar

Lógica invertida (hardware): por causa da montagem mecânica, mindinho/anelar/médio ficam fechados a 180° e abertos a 0°, enquanto o indicador é o oposto (fechado a 0°, aberto a 180°). Isso está documentado na função configurarDedos() do firmware.

### Comunicação BLE (GATT)

Parâmetro | Valor
Nome do dispositivo | MaoRobotica
UUID do serviço | 19b10000-e8f2-537e-4f6c-d104768a1214
UUID da característica (comando) | 19b10001-e8f2-537e-4f6c-d104768a1214
Endereço MAC (exemplo do protótipo) | b4:3a:45:b4:48:11
Payload | 1 byte = código do gesto (ex.: bytearray([7]) )

O MAC precisa ser atualizado em backend/bluetooth_sender.py para o do seu Arduino.

•


Firmware C++: mapeamento de cada configuração de mão para os ângulos dos servos.

## Modelos 3D e peças impressas

A estrutura mecânica é impressa em 3D (PETG) e parte do ecossistema aberto InMoov, com adaptações próprias da
equipe (roldana sob medida, ajustes de encaixe e da caixa do pulso). Os arquivos | .stl | produzidos/utilizados estão
versionados no repositório em | docs/3d_parts/ | .

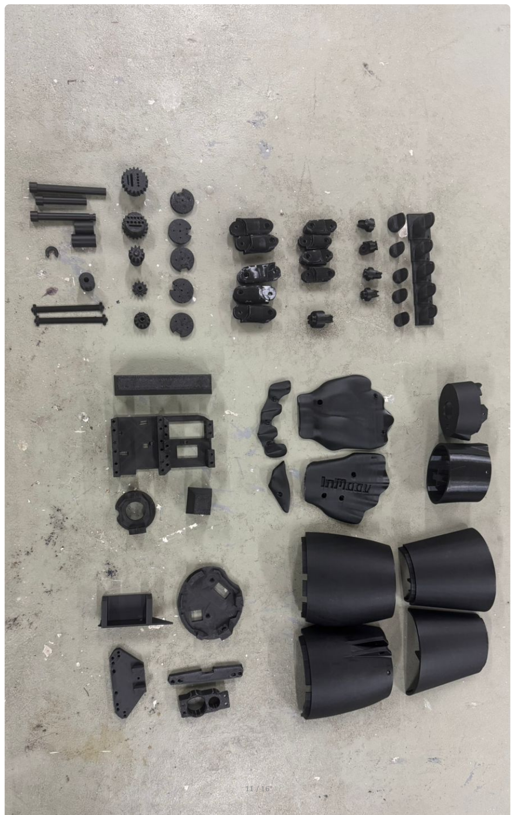
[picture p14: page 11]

Conjunto de peças impressas em PETG antes da montagem (mão, dedos, pulso e suporte).

Mão e dedos — docs/3d_parts/mao/

i2_FingersX5V2 , i2_FingersTipX5V2 , i2_FingersMoldX5V3 , i2_CoverFingerV3 , i2_HandCoverV1 , i2_HandCoverV2 , i2_PalmCoverV2 , i2_WristGearV1 , i2_WristLargeV2 .

Pulso e antebraço — docs/3d_parts/pulso/

robpart2V4 , robpart3V4 , robpart4V4 , robpart5V4 , robcap3V2 , RobRingV3 , RobServoBedV6 , RobCableFrontV3 , RobCableBackV3 , RotaWrist1V4 , RotaWrist2V3 , RotaWrist3V3 , WristGearsV5 , Bolt_entretoise7 .

Suporte — docs/3d_parts/suporte/

Hand_stand.3mf (base de apoio para exposição/testes).
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

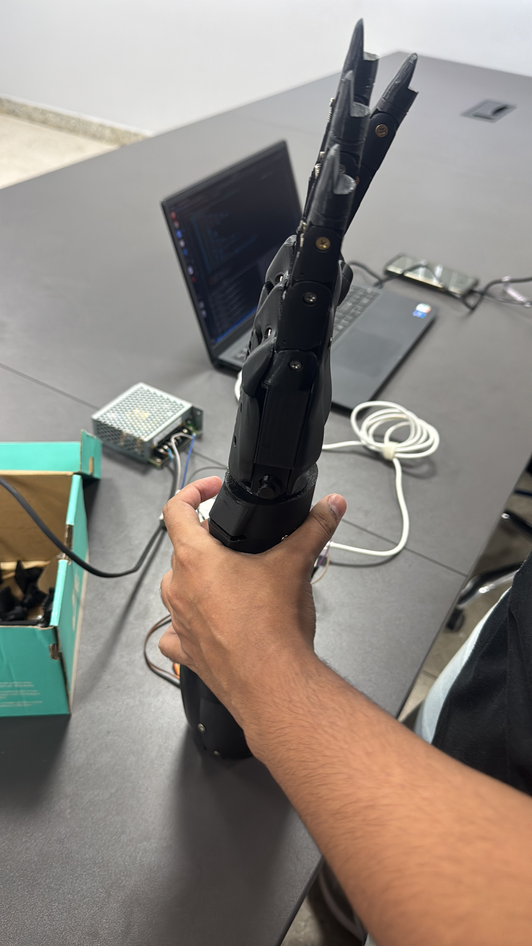
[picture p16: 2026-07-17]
imagens/910489B1-7B6F-4980-B4D8-D9A1898EDD59.JPG

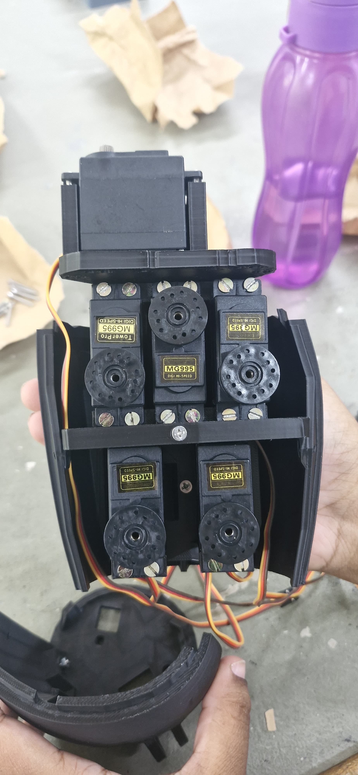
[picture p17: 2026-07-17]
imagens/5b3249cb-c822-431c-8f60-45620334c25a.JPG

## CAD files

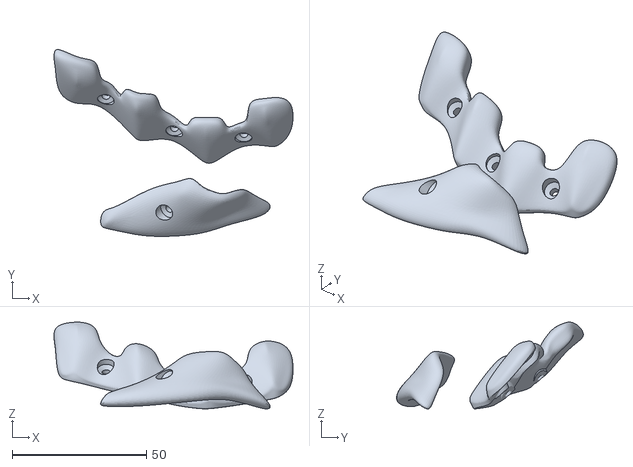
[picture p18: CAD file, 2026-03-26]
docs/3d_parts/mao/i2_CoverFingerV3.stl
89.0 x 69.6 x 32.3

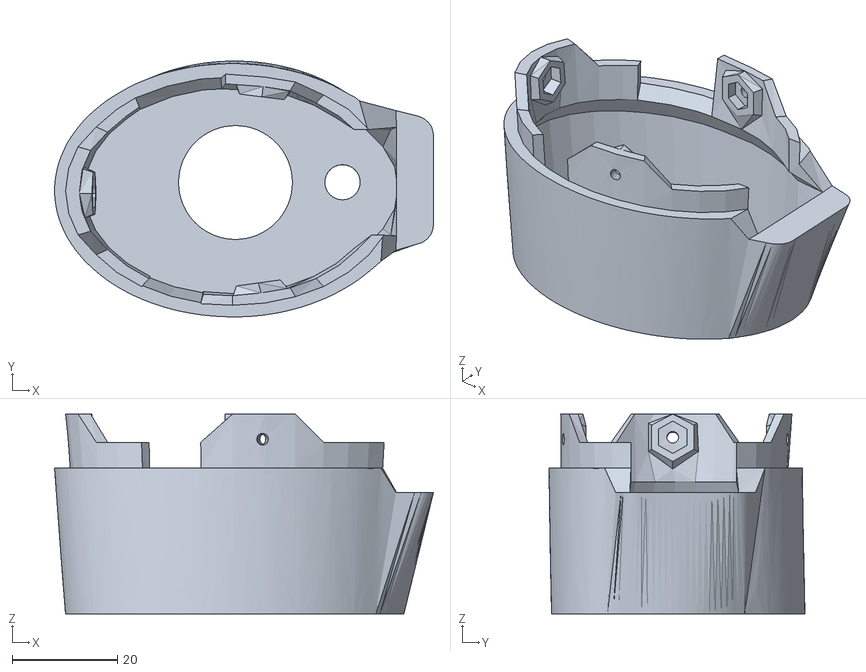
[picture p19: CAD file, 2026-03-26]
docs/3d_parts/pulso/RotaWrist2V3.stl
71.9 x 48.6 x 38.0

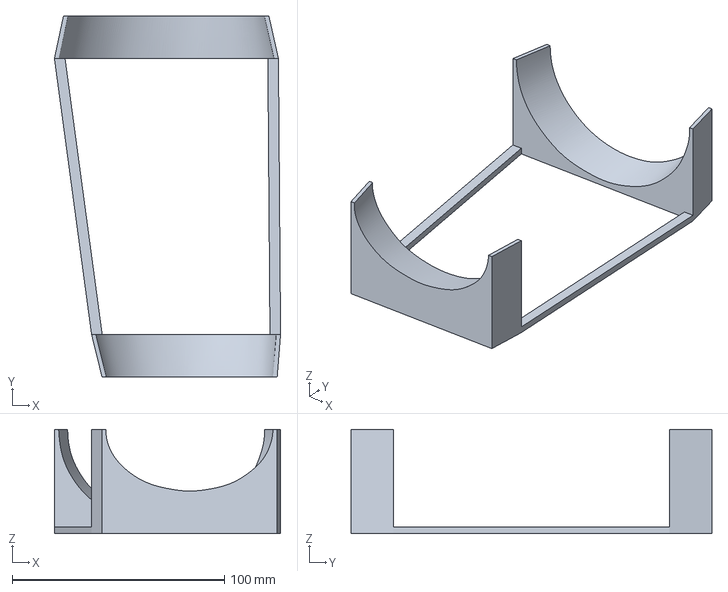
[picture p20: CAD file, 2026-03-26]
docs/3d_parts/suporte/Hand_stand.3mf
106.5 x 170.0 x 49.0 mm

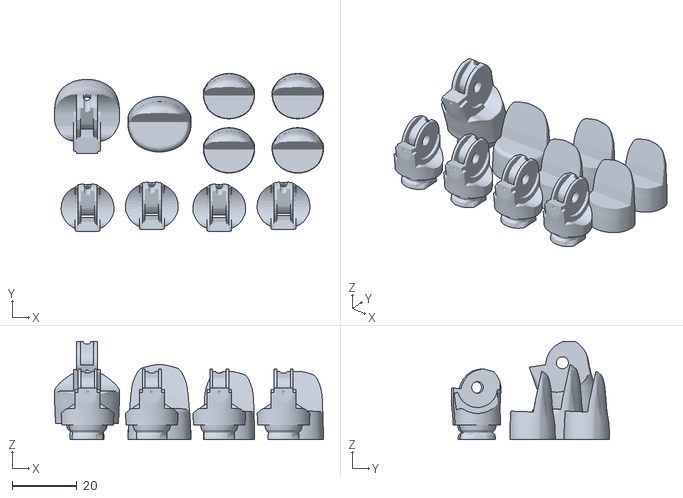
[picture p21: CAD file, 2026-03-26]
docs/3d_parts/mao/i2_FingersTipX5V2.stl
82.9 x 48.7 x 30.2

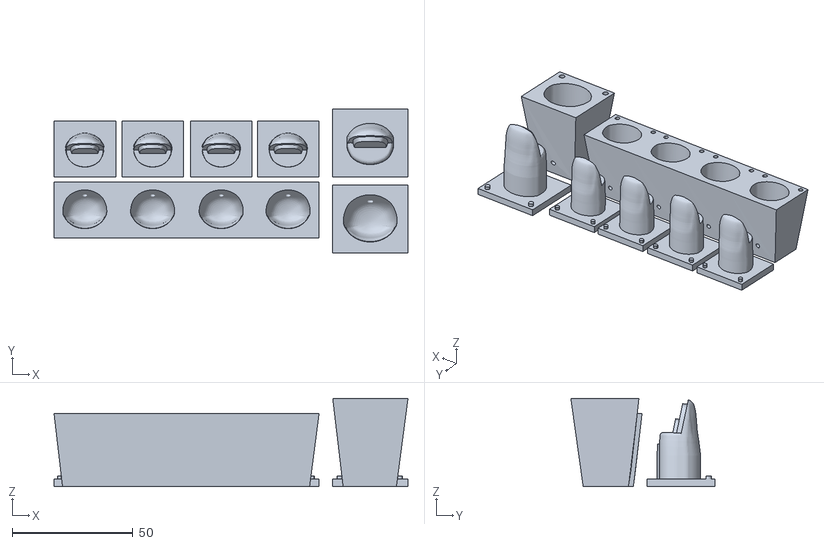
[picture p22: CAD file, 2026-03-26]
docs/3d_parts/mao/i2_FingersMoldX5V3.stl
146.8 x 59.8 x 36.5

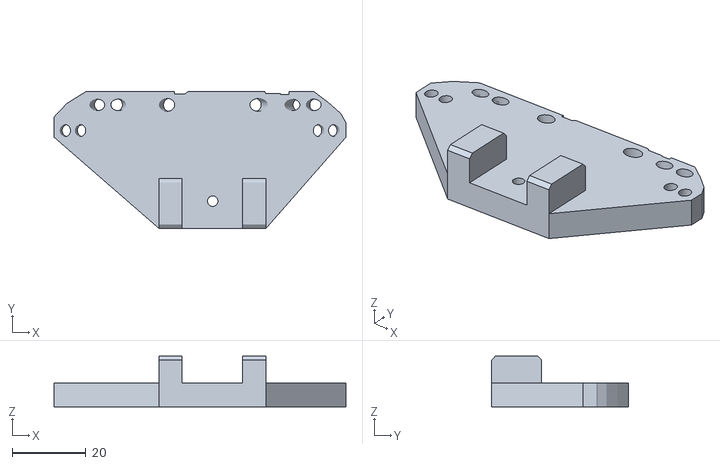
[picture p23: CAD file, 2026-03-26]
docs/3d_parts/pulso/RobCableFrontV3.stl
79.3 x 37.1 x 13.8

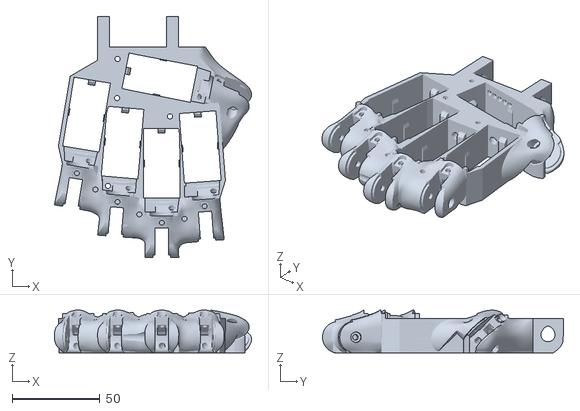
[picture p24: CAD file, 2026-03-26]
docs/3d_parts/mao/i2_WristLargeV2.stl
112.6 x 137.7 x 24.5

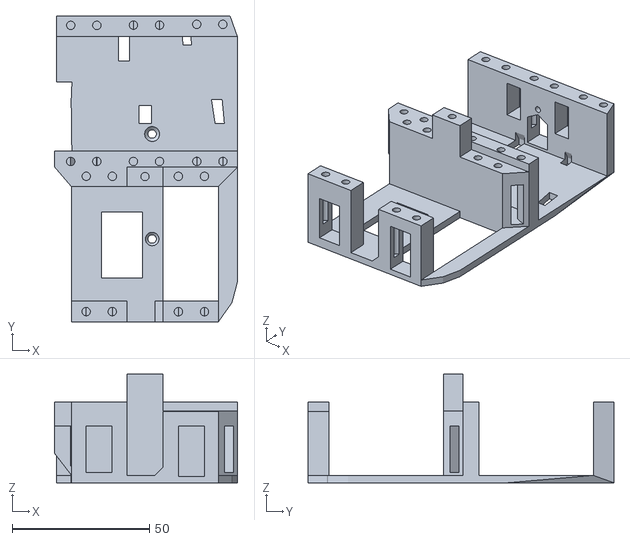
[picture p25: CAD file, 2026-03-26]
docs/3d_parts/pulso/RobServoBedV6.stl
66.7 x 111.6 x 39.7

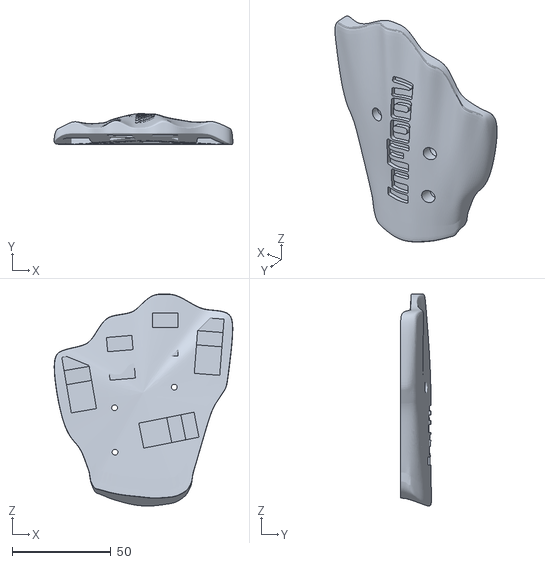
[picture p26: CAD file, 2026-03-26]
docs/3d_parts/mao/i2_HandCoverV2.stl
90.2 x 15.6 x 107.1

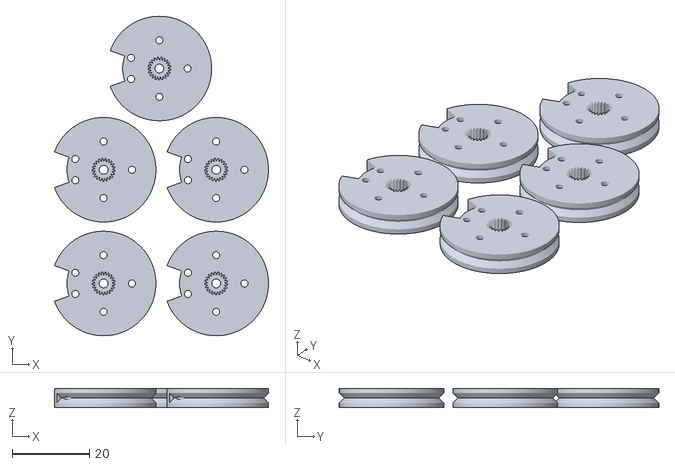
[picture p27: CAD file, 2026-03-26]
docs/3d_parts/pulso/RobRingV3.stl
55.3 x 82.5 x 5.00

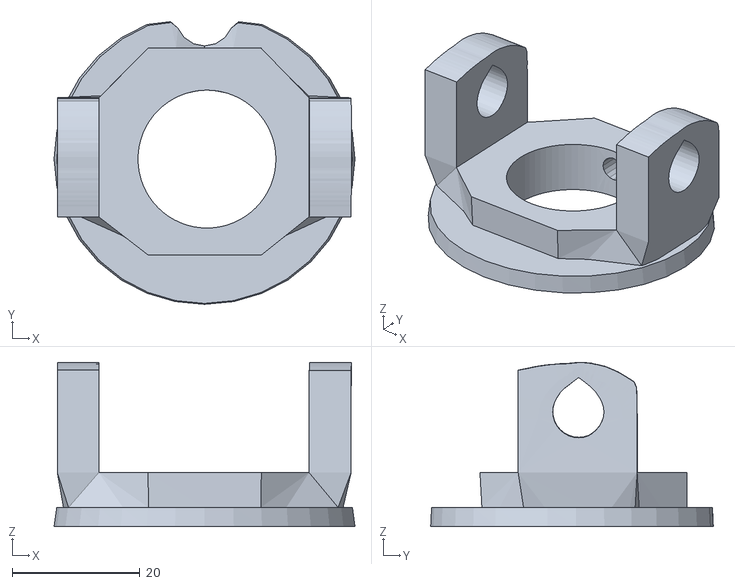
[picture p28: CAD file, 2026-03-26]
docs/3d_parts/pulso/RotaWrist3V3.stl
47.2 x 44.3 x 25.7

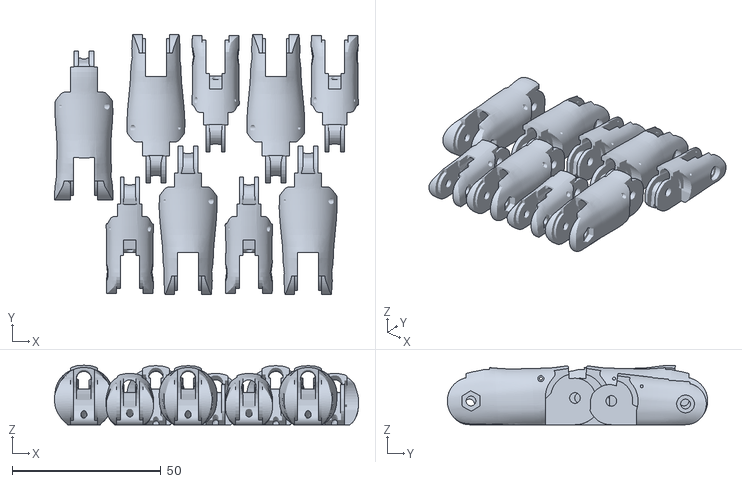
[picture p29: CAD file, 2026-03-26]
docs/3d_parts/mao/i2_FingersX5V2.stl
102.3 x 87.7 x 20.0

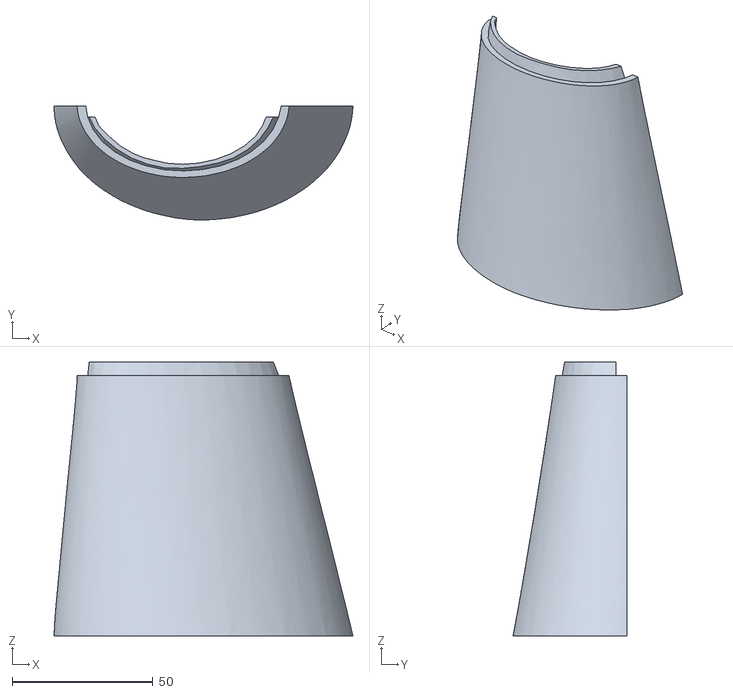
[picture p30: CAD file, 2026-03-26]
docs/3d_parts/pulso/robpart3V4.stl
106.4 x 40.6 x 97.5

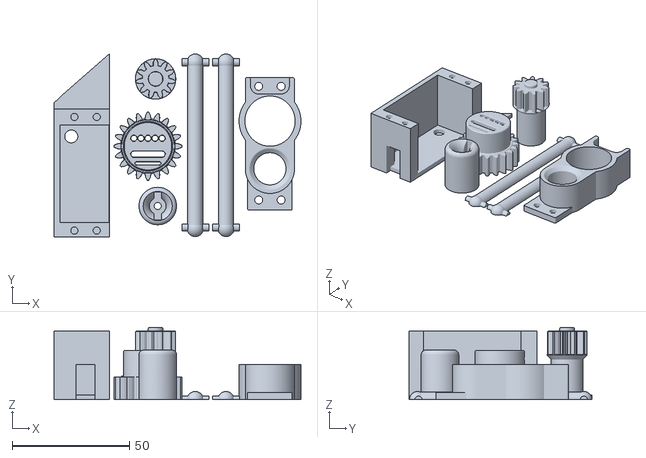
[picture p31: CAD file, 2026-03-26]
docs/3d_parts/mao/i2_WristGearV1.stl
105.2 x 78.1 x 30.8

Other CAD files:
docs/3d_parts/pulso/robpart5V4.stl
docs/3d_parts/mao/i2_PalmCoverV2.stl
docs/3d_parts/pulso/WristGearsV5.stl
docs/3d_parts/pulso/robpart4V4.stl
docs/3d_parts/mao/i2_HandCoverV1.stl
docs/3d_parts/pulso/Bolt_entretoise7.stl
docs/3d_parts/pulso/RobCableBackV3.stl
docs/3d_parts/pulso/RotaWrist1V4.stl
docs/3d_parts/pulso/robcap3V2.stl
docs/3d_parts/pulso/robpart2V4.stl

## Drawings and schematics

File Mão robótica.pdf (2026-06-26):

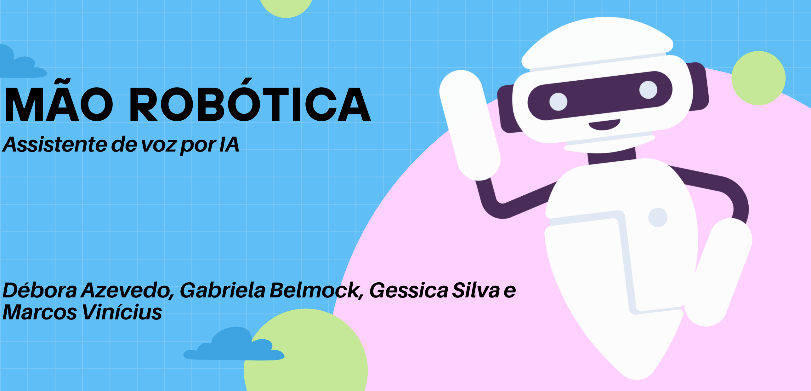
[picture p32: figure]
MÃO ROBÓTICA; Assistentede vozporIA; Marcos Vinícius

## DéboraAzevedo, GabrielaBelmock, Gessica Silva e

# MOTIVAÇÃO

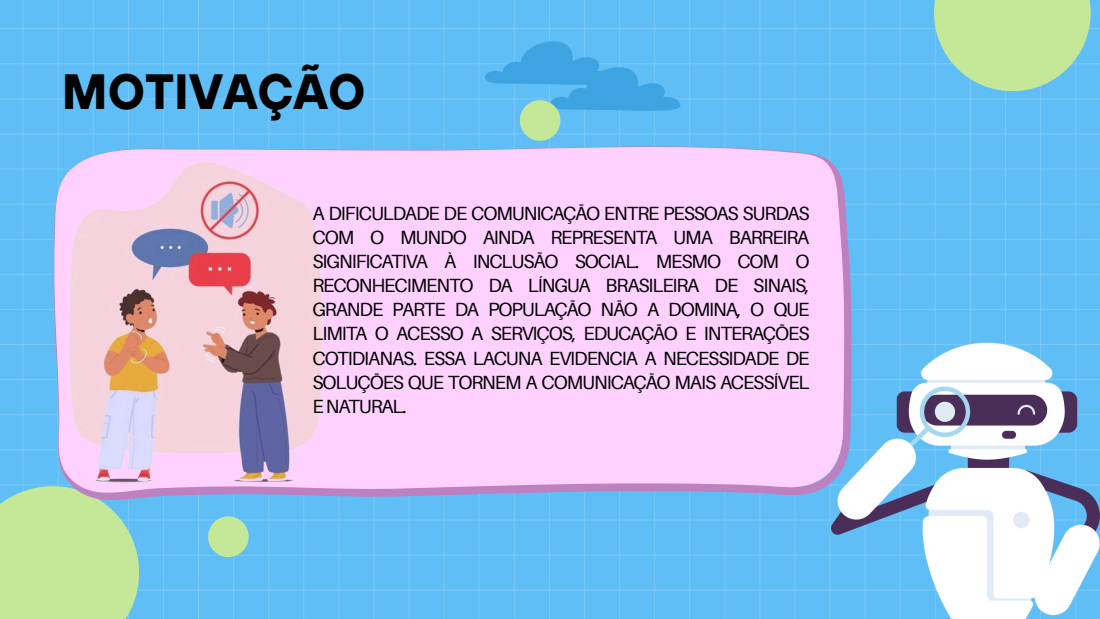
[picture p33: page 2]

A DIFICULDADE DE COMUNICAÇÃO ENTRE PESSOAS SURDAS
COM O MUNDO AINDA REPRESENTA UMA BARREIRA
SIGNIFICATIVA À INCLUSÃO SOCIAL. MESMO COM O
RECONHECIMENTO DA LÍNGUA BRASILEIRA DE SINAIS,
GRANDE PARTE DA POPULAÇÃO NÃO A DOMINA, O QUE
LIMITA O ACESSO A SERVIÇOS, EDUCAÇÃO E INTERAÇÕES
COTIDIANAS. ESSA LACUNA EVIDENCIA A NECESSIDADE DE
SOLUÇÕES QUE TORNEM A COMUNICAÇÃO MAIS ACESSÍVEL
ENATURAL.

# TECNOLOGIAS DO MUNDO ACADÊMICO

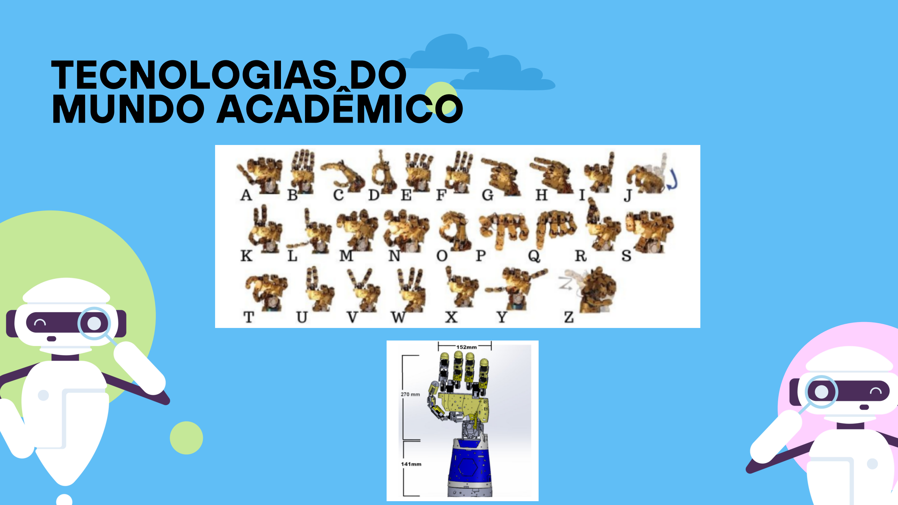
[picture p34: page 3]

# O PROTÓTIPO

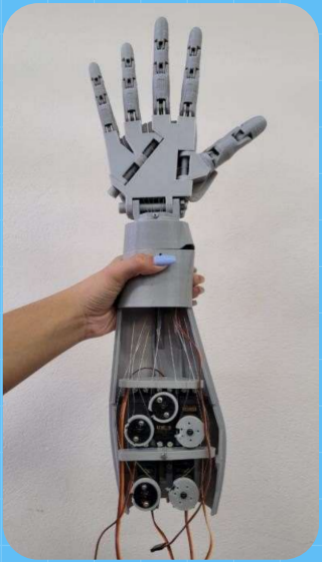
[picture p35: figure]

Sistema de rotação de pulso

5 dedos funcionais

Baixo custo comparado à indústria

Comunicação e acessibilidade

# O PROTÓTIPO

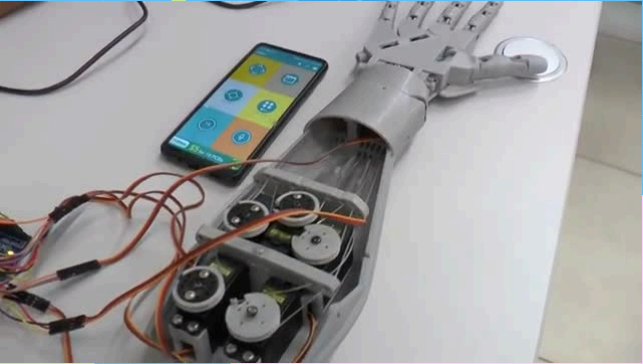
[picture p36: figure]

# O SOFTWARE

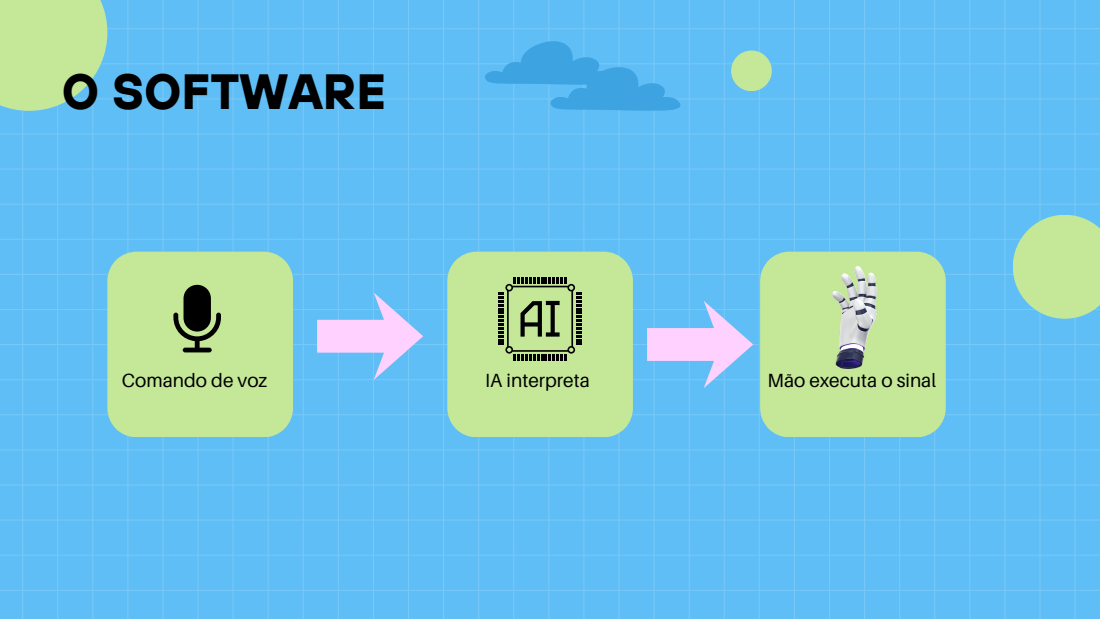
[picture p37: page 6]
Comando de voz; IA interpreta; Mão executa o sinal

# O SOFTWARE

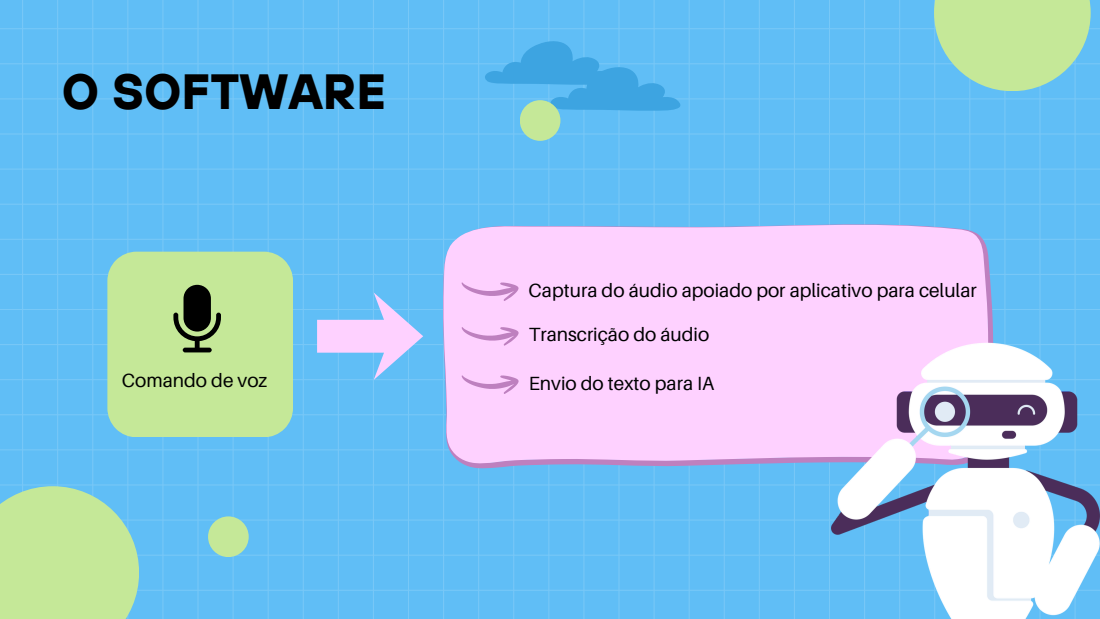
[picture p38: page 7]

Captura do áudio apoiado por aplicativo para celular

Transcrição do áudio

Comando de voz

Envio do texto para IA

# O SOFTWARE

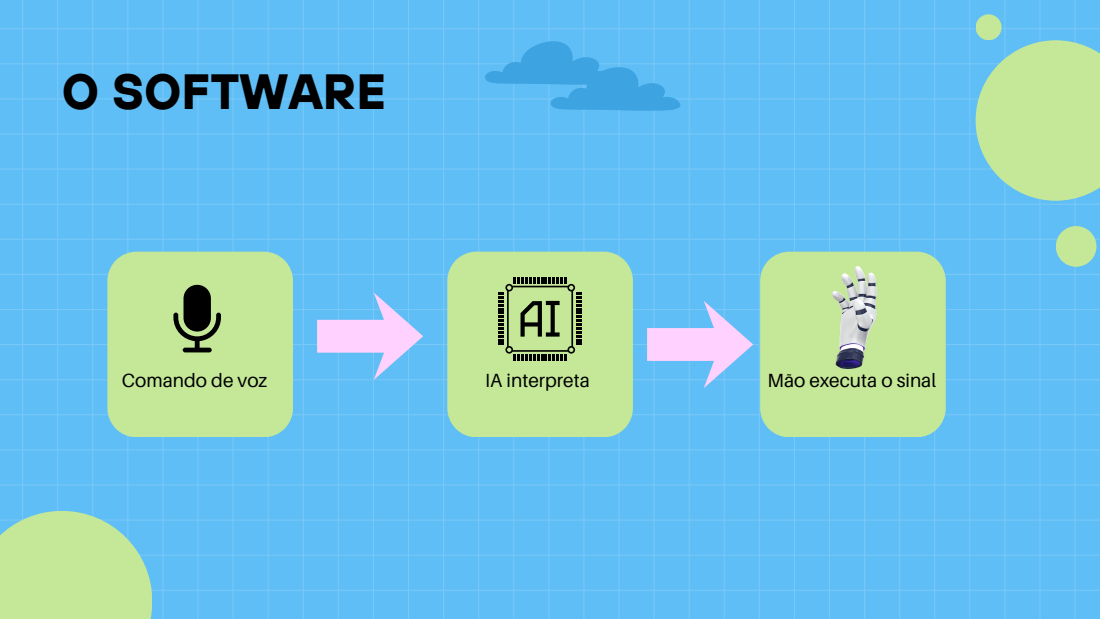
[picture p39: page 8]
Comando de voz; IA interpreta; Mão executa o sinal

# O SOFTWARE

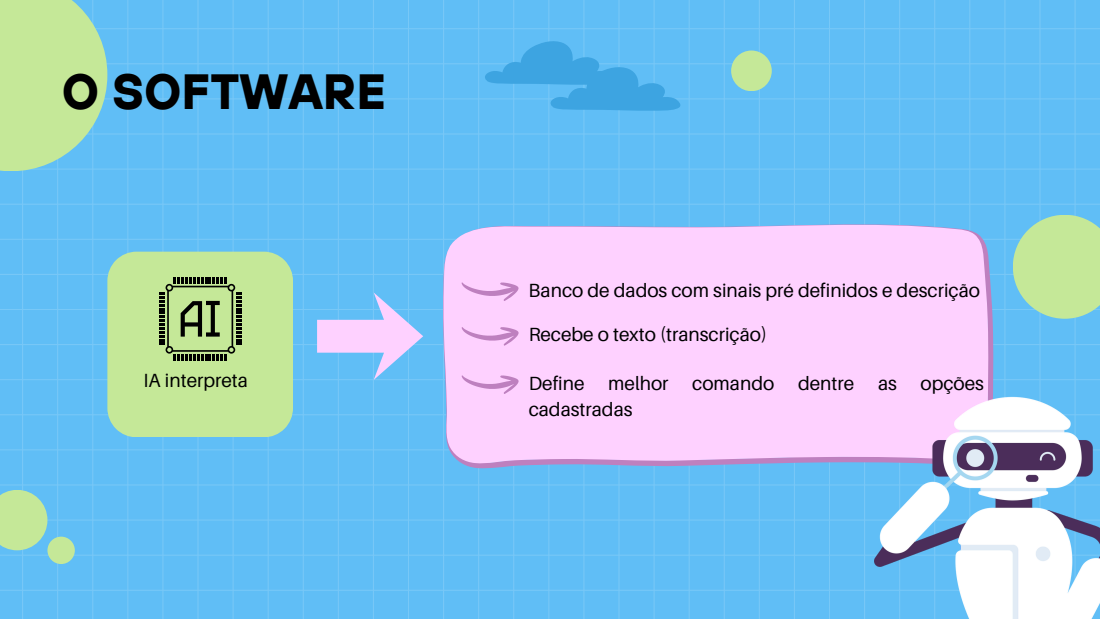
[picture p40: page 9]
IA interpreta

Banco de dados com sinais pré definidos e descrição

Recebe o texto (transcrição)

Define melhor comando dentre as opções
cadastradas

# O SOFTWARE

# O SOFTWARE

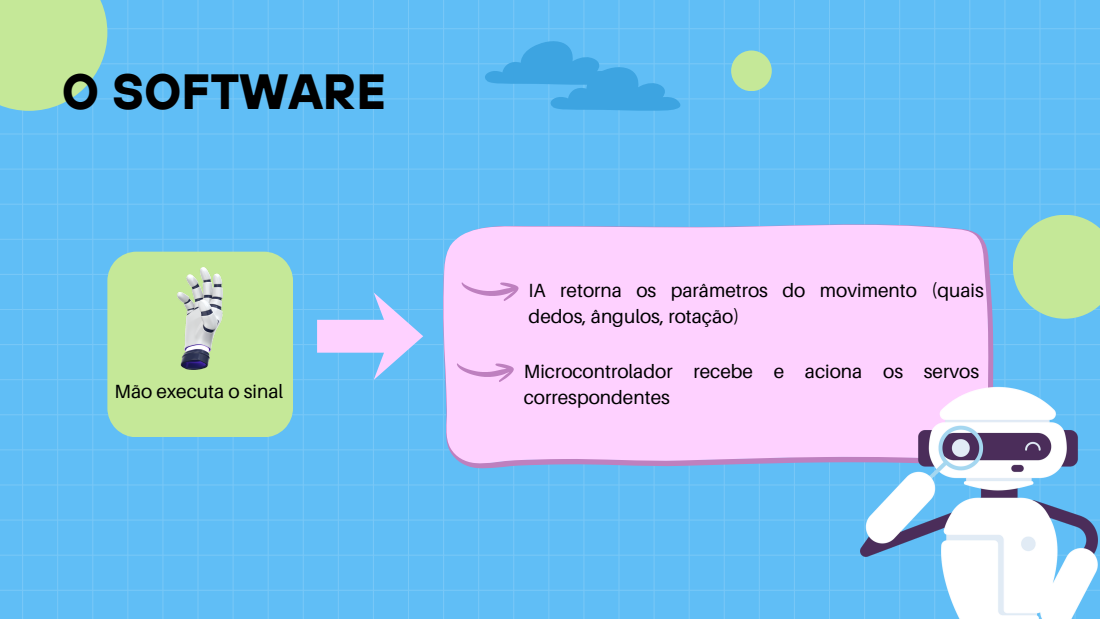
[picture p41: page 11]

IA retorna os parâmetros do movimento (quais
dedos, ângulos, rotação)

Microcontrolador recebe e aciona os servos
correspondentes

Mão executa o sinal

# MATERIAIS

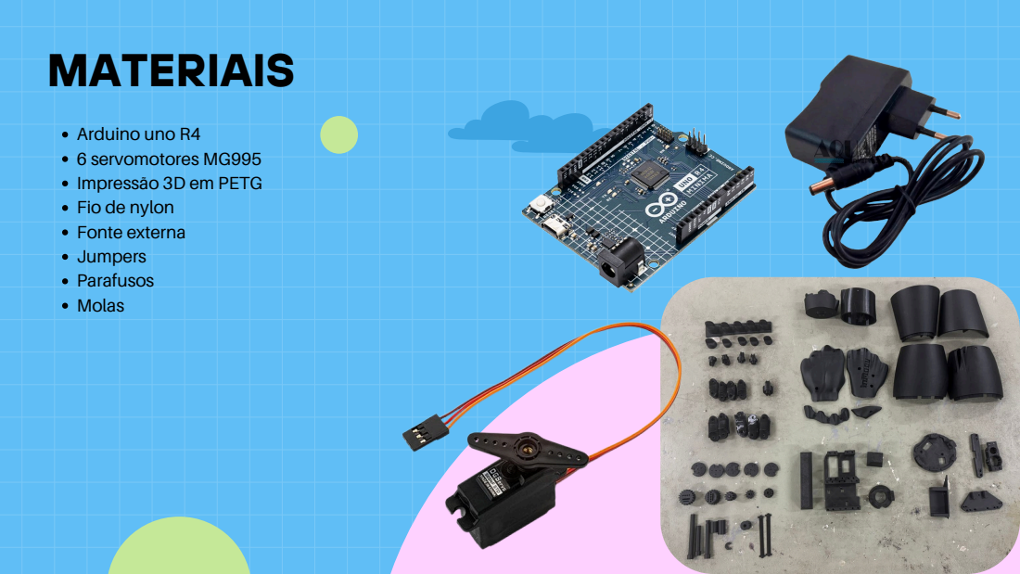
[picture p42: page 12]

Arduino uno R4
6 servomotores MG995
Impressão 3D em PETG
Fio de nylon
Fonte externa
Jumpers
Parafusos
Molas

Custo | Valor
Arduino R4 | R$200,00
6 Servomotores | R$300, 00
Impressão 3D | R$550,00
Fio de Nylon | R$5, 00

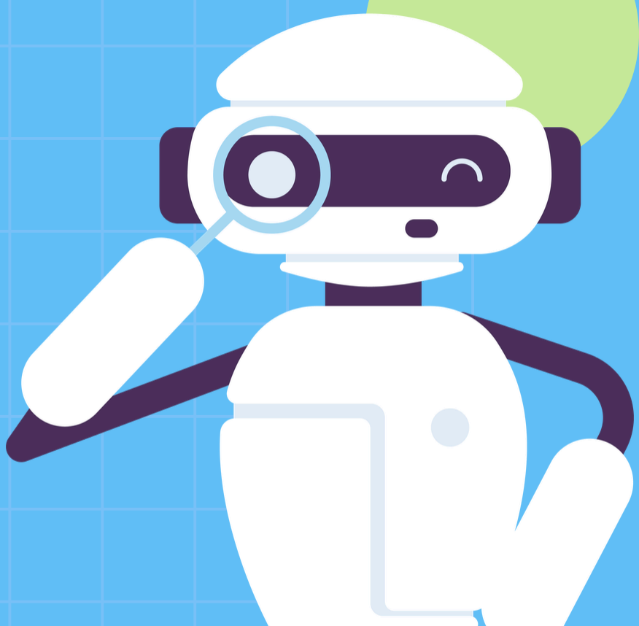
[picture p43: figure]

Fonte externa | R$15, 00
Parafusos e molas | R$35, 00
Total | R$1105, 00

# PREVISÃO DE CUSTOS

# TECNOLOGIAS

## Interface e Experiênciado Utilizador(Mobile):

Flutter; (Dart):; Desenvolvimento; aplicativo

multiplataforma com interface de chatbot em tempo real.
Speech-to-Text (STT): Utilização de pacotes nativos do
Flutter para captura e transcrição de comandos de voz.
Comunicação API: Integração via protocolo HTTP/JSON
para envio de texto e receção de respostas da IA.

# TECNOLOGIAS

## Integraçãode Sistema

InteligênciaArtificial e Processamento:

Python (Backend): Servidor intermédio para processar a
lógica pesada e comunicar com o Arduino via Porta
Serial.

Ollama (LLM Local): Orquestração de modelos de
linguagem para interpretação de intenções.
Prompt Engineering: Mapeamento de linguagem
natural para parâmetros técnicos de movimento
(ângulos e dedos específicos).

# TECNOLOGIAS

## Controle e HardwaredeBaixo Nível:


Linguagem C++: Programação do microcontrolador
para gestão de lógica de movimento e temporização.
Arduino Uno R4: Processamento dos sinais recebidos e
controlo PWM para os motores.
Biblioteca Servo.h: Coordenação dos 6 servomotores
MG995 de forma simultânea.

OBRIGADO =)

# CRONOGRAMA


# CRONOGRAMA


# ESTADO ATUAL


# ESTADO ATUAL


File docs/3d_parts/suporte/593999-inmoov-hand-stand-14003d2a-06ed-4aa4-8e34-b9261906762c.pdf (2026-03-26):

Model files; Summary; Hobby & Makers; RC & Robotics; Tags: stand; robot; inmoov; bloudakm; updated 25. 9. 2023 | published 25. 9. 2023; hand_stand.3mf; 3D MODEL ONLY

Inmoov hand stand

VIEW IN BROWSER (https://printables.com/model/593999-inmoov-hand-stand)

A useful stand which can be used if you are only using the inmoov hand
without the rest of the body.

### License

This work is licensed under a
Creative Commons (International License)

Public Domain (https://creativecommons.org/share-your-work/public-domain/cc0/)

✔ | Sharing without ATTRIBUTION
✔ | Remix Culture allowed
✔ | Commercial Use
✔ | Free Cultural Works
✔ | Meets Open Definition

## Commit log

2026-03-26 pecas 3d
    [Bolt_entretoise7.stl, RobCableBackV3.stl, RobCableFrontV3.stl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]
2026-04-02 Add servo control code for six servos
    Implement servo control for six servos with sweeping motion.
2026-04-09 Add BLE service for LED control
    Implementa um serviço BLE para controle de LED via Bluetooth.
2026-04-09 configuracao pastas
    [Bolt_entretoise7.stl, Hand_stand.3mf, RobCableBackV3.stl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]
2026-04-30 feat: atualiza infraestrutura Android, otimiza microfone e expande interface
    - Atualiza versão do Kotlin e compileSdk (36) para compatibilidade com o pacote speech_to_text.
    - Implementa modo imersivo (tela cheia) ocultando a barra de navegação nativa do Android.
    - Adiciona trava de estado (lock) na leitura de voz para evitar envio duplicado de áudio.
    - Cria fluxo visual de status da Mão ('Analisando...' e 'Executando movimento...') no chat.
    - Adiciona AppBar com menu de navegação e as estruturas iniciais das telas de Biblioteca e Cadastro de Sinais.
    - Atualiza o README.md com o tutorial de execução em smartphone físico.
2026-06-26 ajuste ip arduino
2026-06-28 ajustes de ip
2026-07-04 Restaura versão funcional da comunicação do Arduino
2026-07-04 Corrige restauração: traz arquivos da versão d1184ce do Arduino
2026-07-04 Corrige restauração: traz arquivos da versão 56da203 do Arduino
2026-07-04 tentando resolver confusao do codigo do arduino
2026-07-04 codigo do arduino teste1
2026-07-05 resposta de IA melhorada
2026-07-08 biblioteca de gestos
2026-07-09 ajustes finais
    [pyvenv.cfg]
